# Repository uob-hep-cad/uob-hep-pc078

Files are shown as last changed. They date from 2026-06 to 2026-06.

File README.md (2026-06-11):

# uob-hep-pc078

XLZD OD preamplifier based on XENONnT design

Based on circuit in J. Wulf, Direct Dark Matter Search with XENON1T and Developments for Multi-Ton Liquid Xenon Detectors

[Circuit Schematic](./hardware/KiCAD/xlzd_xenonnt_amplifier_test/xlzd_xenonnt_amplifier_test_schematic_8jun26_01.pdf)

3D rendering of PCB:
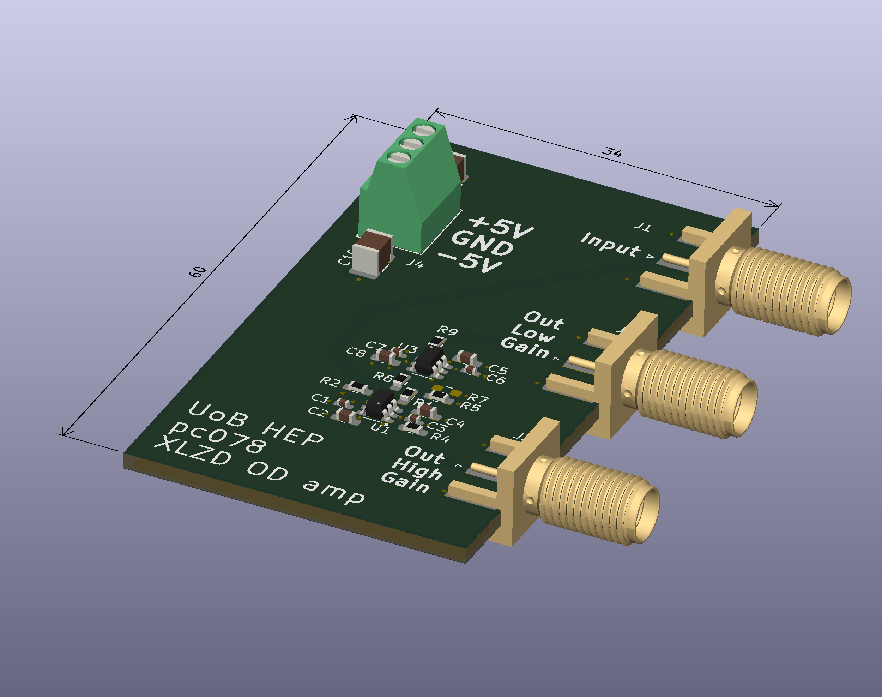
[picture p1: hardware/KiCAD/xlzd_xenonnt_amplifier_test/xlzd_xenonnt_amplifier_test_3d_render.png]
3D render of PCB


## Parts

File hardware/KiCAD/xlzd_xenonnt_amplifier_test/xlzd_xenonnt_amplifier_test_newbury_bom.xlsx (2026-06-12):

Description | Qty per BOM | Quantity per batch | Min Quantity to order | Manufacturer | Manufacturer Part Number | Supplier | Supplier Part Number | Designator | Package Type | Technology | Comment | Status | Original Manufacturer Part No from client BOM
CAPACITOR; 0402; 50V; 10%; X7R; -55+125C | 4 | 12 | 12 |  | 0402-1nF-50V | Newbury free stock | 0402-1nF-50V | C1,C3,C6,C7 |  | SMD |  | Newbury free stock | 1n
CAPACITOR; 0603; 50V; 10%; X7R; -55+125C | 4 | 12 | 12 |  | 0603-100nF-50V | Newbury free stock | 0603-100nF-50V | C2,C4,C5,C8 |  | SMD |  | Newbury free stock | 100n
1210 10UF 50V 20% X7R | 2 | 6 | 6 | KYOCERA AVX | 12105C106MAT2A | ANGLIA | 961002001 | C9,C10 | Tape & Reel | SMD |  | Found | 10u
CONN SMA RCPT STR 50OHM EDGE MNT | 3 | 9 | 9 | Amphenol RF | 132289 | DIGIKEY | ACX1426-ND | J1,J2,J3 | Bag | SMD |  | Found | Conn_Coaxial
Conn PC Terminal Block 3 POS 2.54mm Solder ST Thru-Hole 6A | 1 | 3 | 3 | Phoenix Contact | MPT 0.5/ 3-2.54 | ARROW | 0323_01944018 | J4 | BOX | THT |  | Found | Screw_Terminal_01x03
RESISTOR; 0603; 0.1W; 100ppm; 1%; 75V; -55+125C | 3 | 9 | 9 |  | 0603-27R | Newbury free stock | 0603-27R | R1,R2,R6 |  | SMD |  | Newbury free stock | 27R
RESISTOR; 0201; 0.05W; 200ppm; 1%; 25V; -55+125C; | 1 | 3 | 3 |  | 0201-510R | Newbury free stock | 0201-510R | R3 |  | SMD |  | Newbury free stock | 510R
RESISTOR; 0603; 0.1W; 100ppm; 1%; 75V; -55+125C | 3 | 9 | 9 |  | 0603-51R | Newbury free stock | 0603-51R | R4,R5,R9 |  | SMD |  | Newbury free stock | 51R
TEXAS INSTRUMENTS - OPA847IDBVT - Operational Amplifier, 1 Channels, 3.9 GHz, 950 V/µs, ± 5V to ± 6V, SOT-23, 6 Pins | 1 | 3 | 3 | TEXAS INSTRUMENTS | OPA847IDBVT | FARNELL | 3005071 | U1 | Cut Tape | SMD |  | Found | OPA847xDBV
Video Amplifiers Wideband Fixed Gain Buffer A 595-OPA692I A 595-OPA692IDBVT | 1 | 3 | 3 | Texas Instruments | OPA692IDBVR | MOUSER | 595-OPA692IDBVR | U3 | Cut Tape | SMD |  | Found | OPA692xDBV

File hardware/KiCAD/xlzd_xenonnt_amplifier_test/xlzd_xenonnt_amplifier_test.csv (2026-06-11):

Reference | Qty | Value | DNP | Exclude from BOM | Exclude from Board | Footprint | Datasheet
C1,C3,C6,C7 | 4 | 1n |  |  |  | Capacitor_SMD:C_0402_1005Metric_Pad0.74x0.62mm_HandSolder
C2,C4,C5,C8 | 4 | 100n |  |  |  | Capacitor_SMD:C_0603_1608Metric_Pad1.08x0.95mm_HandSolder
C9,C10 | 2 | 10u |  |  |  | Capacitor_SMD:C_1210_3225Metric_Pad1.33x2.70mm_HandSolder
J1,J2,J3 | 3 | Conn_Coaxial |  |  |  | Connector_Coaxial:SMA_Amphenol_132289_EdgeMount
J4 | 1 | Screw_Terminal_01x03 |  |  |  | TerminalBlock_Phoenix:TerminalBlock_Phoenix_MPT-0,5-3-2.54_1x03_P2.54mm_Horizontal
R1,R2,R6 | 3 | 27R |  |  |  | Resistor_SMD:R_0603_1608Metric_Pad0.98x0.95mm_HandSolder
R3 | 1 | 510R |  |  |  | Resistor_SMD:R_0603_1608Metric_Pad0.98x0.95mm_HandSolder
R4,R5,R9 | 3 | 51R |  |  |  | Resistor_SMD:R_0603_1608Metric_Pad0.98x0.95mm_HandSolder
R7,R8 | 2 | OPEN | DNP |  |  | Resistor_SMD:R_0603_1608Metric_Pad0.98x0.95mm_HandSolder
U1 | 1 | OPA847xDBV |  |  |  | Package_TO_SOT_SMD:SOT-23-6 | http://www.ti.com/lit/ds/symlink/opa847.pdf
U3 | 1 | OPA692xDBV |  |  |  | Package_TO_SOT_SMD:SOT-23-6 | http://www.ti.com/lit/ds/symlink/opa847.pdf

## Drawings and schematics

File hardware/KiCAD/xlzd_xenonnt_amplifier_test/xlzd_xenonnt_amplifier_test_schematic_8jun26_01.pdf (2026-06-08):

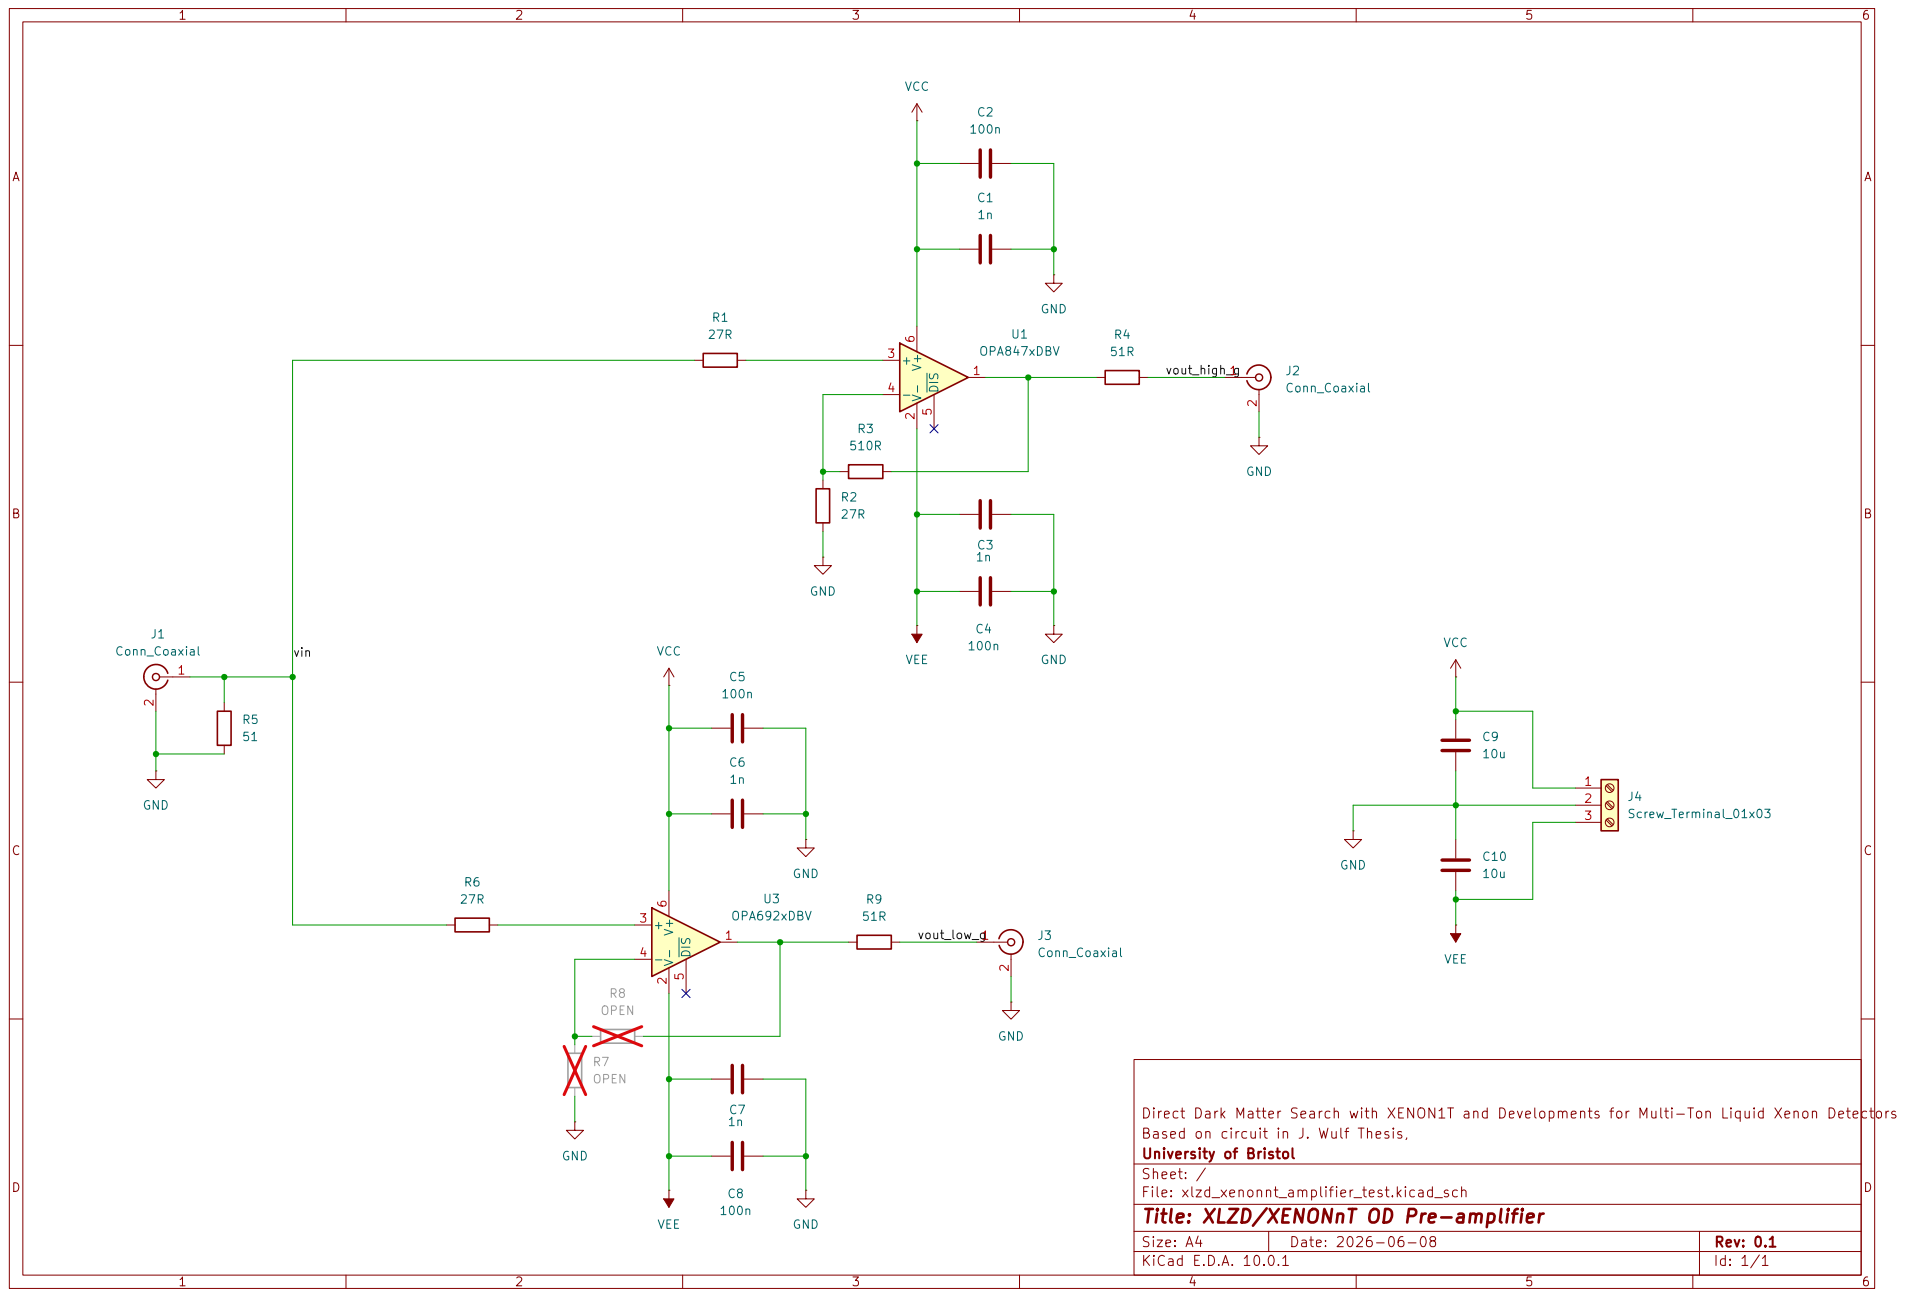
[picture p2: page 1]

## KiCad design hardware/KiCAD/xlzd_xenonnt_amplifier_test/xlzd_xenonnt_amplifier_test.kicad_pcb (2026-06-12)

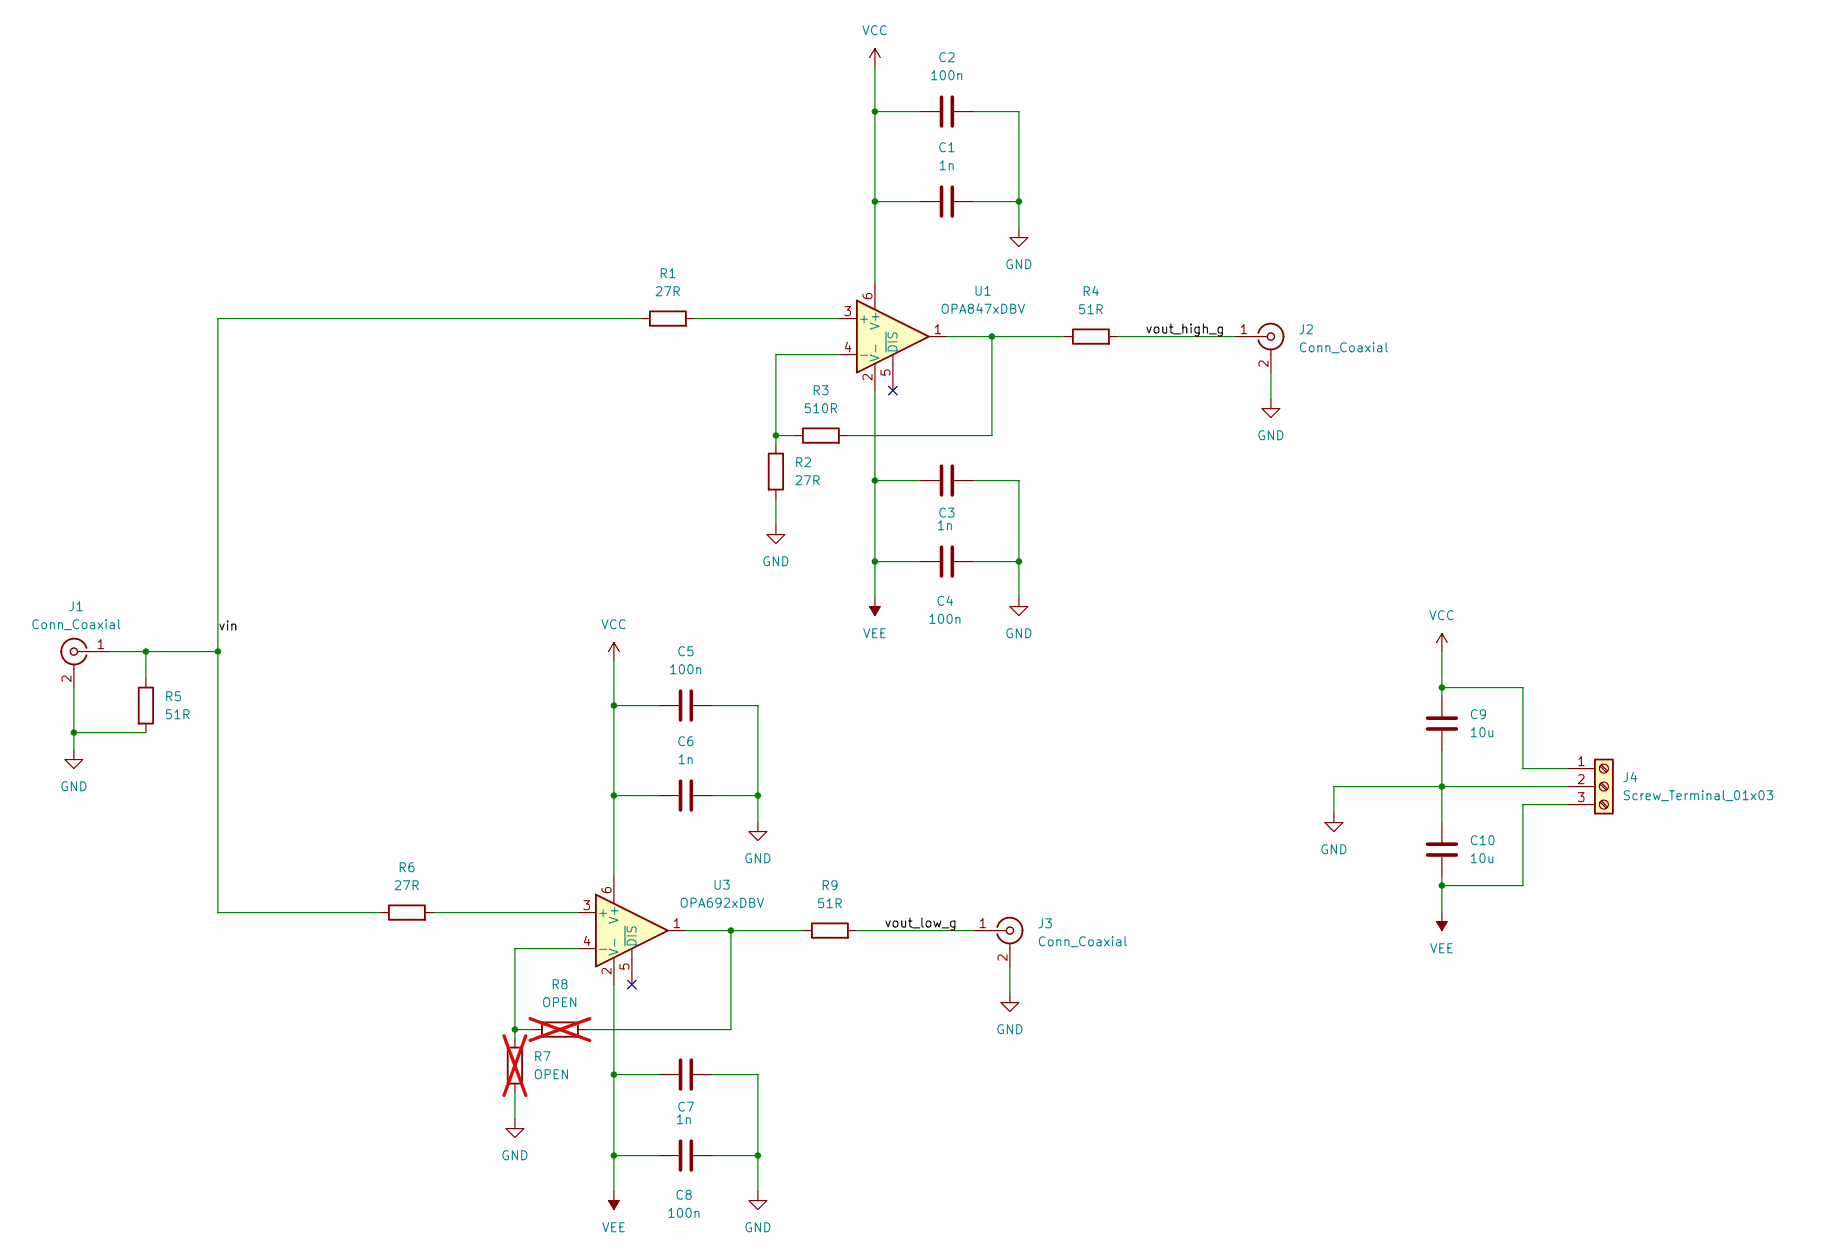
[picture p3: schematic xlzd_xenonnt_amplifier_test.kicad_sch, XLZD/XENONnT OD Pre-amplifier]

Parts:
C1, C3, C6, C7: 1n; C_0402_1005Metric_Pad0.74x0.62mm_HandSolder
C2, C4, C5, C8: 100n; C_0603_1608Metric_Pad1.08x0.95mm_HandSolder
C9, C10: 10u; C_1210_3225Metric_Pad1.33x2.70mm_HandSolder
J1, J2, J3: Conn_Coaxial; SMA_Amphenol_132289_EdgeMount
J4: Screw_Terminal_01x03; TerminalBlock_Phoenix_MPT-0,5-3-2.54_1x03_P2.54mm_Horizontal
R1, R2, R6: 27R; R_0603_1608Metric_Pad0.98x0.95mm_HandSolder
R3: 510R; R_0603_1608Metric_Pad0.98x0.95mm_HandSolder
R4, R5, R9: 51R; R_0603_1608Metric_Pad0.98x0.95mm_HandSolder
R7, R8: OPEN; R_0603_1608Metric_Pad0.98x0.95mm_HandSolder; not fitted
U1: OPA847xDBV; SOT-23-6
U3: OPA692xDBV; SOT-23-6

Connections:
/vin: J1.1 (In), R1.1, R5.1, R6.1
/vout_high_g: J2.1 (In), R4.2
/vout_low_g: J3.1 (In), R9.2
GND: C1.2, C2.2, C3.2, C4.2, C5.2, C6.2, C7.2, C8.2, C9.2, C10.1, J1.2 (Ext), J2.2 (Ext), J3.2 (Ext), J4.2, R2.2, R5.2, R7.2
unnamed: R3.2, R4.1, U1.1
unnamed: R8.2, R9.1, U3.1
unnamed: R1.2, U1.3 (+)
unnamed: R2.1, R3.1, U1.4 (-)
unnamed: R6.2, U3.3 (+)
unnamed: R7.1, R8.1, U3.4 (-)
VCC: C1.1, C2.1, C5.1, C6.1, C9.1, J4.1, U1.6 (V+), U3.6 (V+)
VEE: C3.1, C4.1, C7.1, C8.1, C10.2, J4.3, U1.2 (V-), U3.2 (V-)

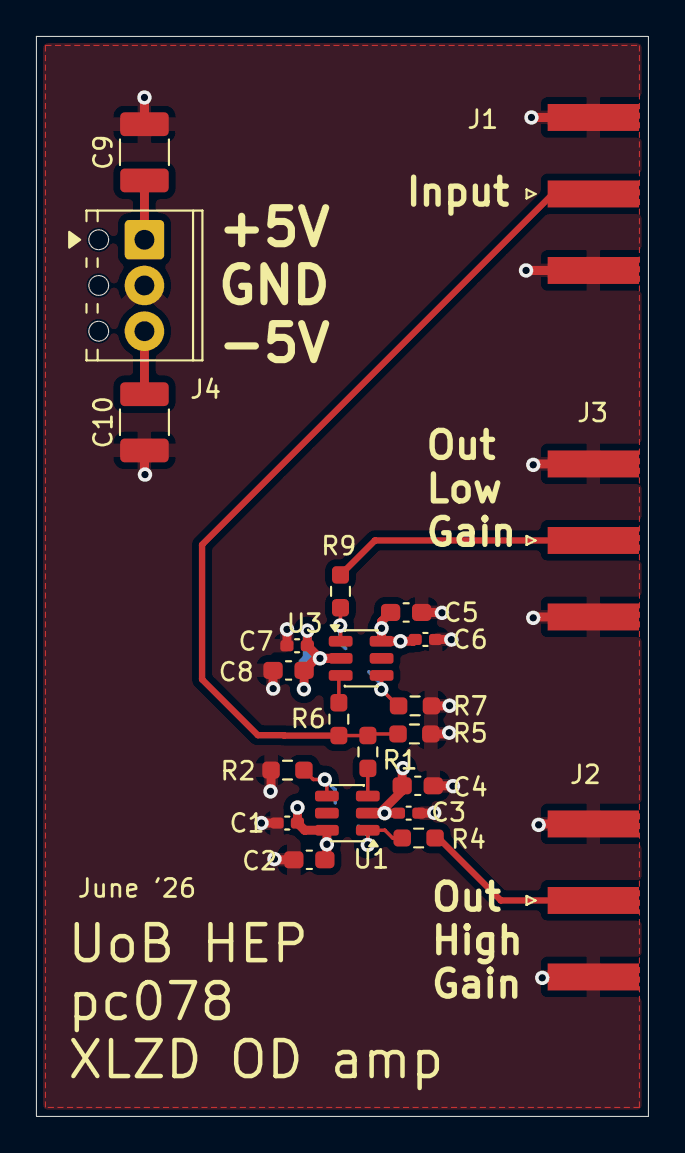
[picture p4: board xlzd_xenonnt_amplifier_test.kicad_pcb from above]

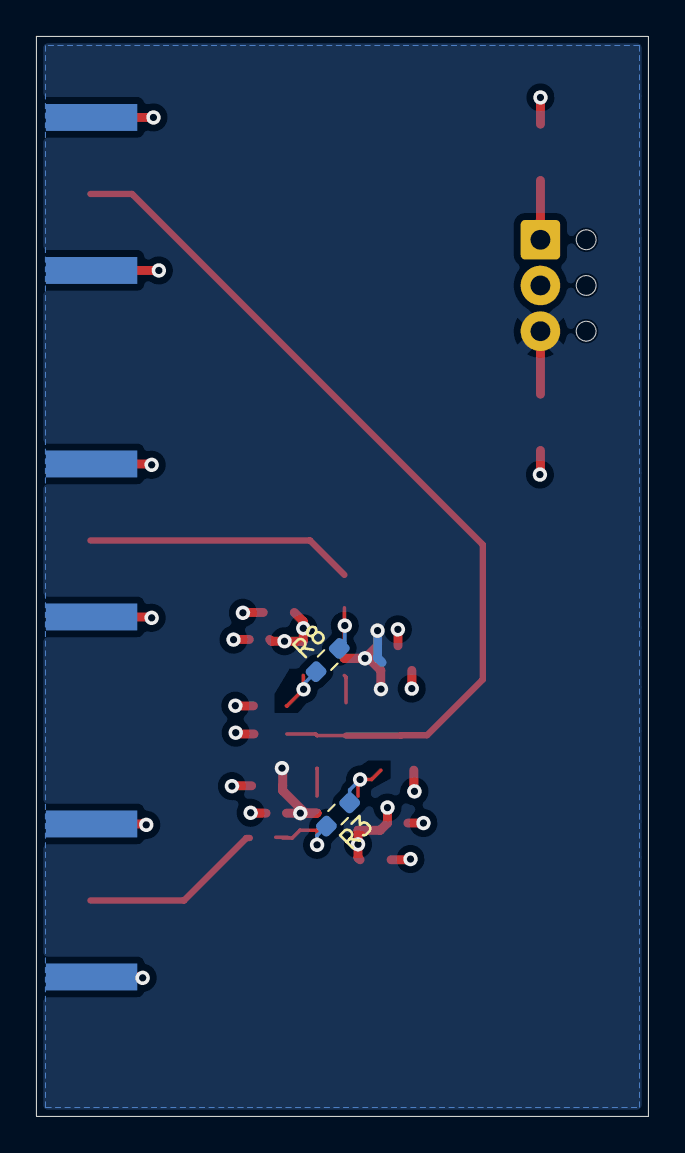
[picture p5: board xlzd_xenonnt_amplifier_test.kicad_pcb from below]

Board: 4 copper layers, 34.0 x 60.0 mm, 25 parts (2 on the bottom side), 12 nets.

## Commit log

2026-06-08 First commit. PCB routed.
    [xlzd_xenonnt_amplifier_test.kicad_pcb, xlzd_xenonnt_amplifier_test.kicad_sch]
2026-06-08 Generated manufacturing artwork
    [xlzd_xenonnt_amplifier_test-B_Cu.gbr, xlzd_xenonnt_amplifier_test-B_Mask.gbr, xlzd_xenonnt_amplifier_test-B_Paste.gbr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]
2026-06-08 Tidied up silkscreen. Added fabrication drawings to Gerber job
    [xlzd_xenonnt_amplifier_test-B_Cu.gbr, xlzd_xenonnt_amplifier_test-B_Fab.gbr, xlzd_xenonnt_amplifier_test-B_Mask.gbr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]
2026-06-11 Added 3D render
    [xlzd_xenonnt_amplifier_test.csv, xlzd_xenonnt_amplifier_test.kicad_sch]
2026-06-11 More-or-less sorted out links to schematic and 3D render (Update README.md)
2026-06-12 Added voids to planes underneath inverting input to op-amps. Regenerated artwork. Created Zip archive
    [xlzd_xenonnt_amplifier_test-B_Cu.gbr, xlzd_xenonnt_amplifier_test-B_Fab.gbr, xlzd_xenonnt_amplifier_test-B_Mask.gbr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]
